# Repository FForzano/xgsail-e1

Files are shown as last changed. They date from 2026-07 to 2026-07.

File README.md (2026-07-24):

# XGSail-E1



E1 device firmware and hardware for [XGSail](https://github.com/FForzano/xgsail) —
an ESP32 sailboat tracker: GNSS + IMU + wind + pressure logging, an
ESP-NOW peer mesh for live fleet position sharing and on-course-side
(OCS) race-start detection, and uploads over the XGSail device
protocol — direct over WiFi, or relayed over BLE by the owner's phone
when WiFi isn't available.

> **xgsail-e1 is derived from `sailframes/core`**, the upstream hardware/
> firmware project. It is not a GitHub fork of that repository (see
> "Relationship to SailFrames Core" below for why, and where this
> content actually came from) — it's a from-scratch export of the E1
> device's firmware and hardware, reorganized into per-responsibility
> modules and stripped down to E1 only.

## What xgsail-e1 Is

xgsail-e1 is the firmware and PCB design for one specific device: **E1**,
an ESP32-based fleet tracker.

It provides:

- Firmware (`firmware/sailframes_edge/`) — GNSS/IMU/wind/pressure sensor
  reads, SD-card session logging, an ESP-NOW peer mesh with on-course-side
  (OCS) race-start detection, the XGSail device-protocol claim/upload flow
  (direct over WiFi and a BLE GATT relay for when WiFi isn't available),
  and a serial/telnet console.
- Hardware (`hardware/`) — the KiCad 8+ schematic, PCB layout, Gerbers,
  and BOM for the E1 board.
- Documentation (`docs/`) — the firmware's internal architecture, GNSS/RTK
  configuration and PPK post-processing workflow, and the current battery/
  display/power hardware.

The device talks to the XGSail backend through the hardware-agnostic
ingestion contract documented in xgsail's `docs/device-protocol.md`
(device claim, `DeviceKey` auth, presigned session uploads, and the BLE
relay contract for WiFi-less operation) — this repo implements that
contract, it doesn't redefine it.

## What xgsail-e1 Is Not

xgsail-e1 is **not** the software platform — users, roles, clubs, the
ingestion API, analytics, or the web/native apps. That's
[XGSail](https://github.com/FForzano/xgsail).

It is also not the general SailFrames Core hardware project: other
device families from that upstream (a Raspberry-Pi-based "Edge-S" unit,
a sealed-enclosure successor board, and a standalone BLE wind-sensor
accessory) are out of scope here on purpose — this repository is E1 only.

## Relationship to SailFrames Core

XGSail's own `xgsail` repository is itself a GitHub-level fork of
`sailframes/core`, the upstream hardware+software monorepo — before its
software layer was redesigned into what is now XGSail, that repository's
history contained `edge-e/` (the E1 device: this firmware + hardware),
`edge-b/` (a later, different hardware platform), and `edge-s/` (the
Raspberry-Pi device), alongside the cloud-side code that became XGSail's
backend/frontend/workers.

xgsail-e1 is an export of `edge-e/` from that history: the firmware and
hardware for E1 specifically, with the other device families and the
now-superseded cloud-side code left out, and the firmware's `#ifdef`s for
the non-E1 hardware variant removed rather than carried forward as dead
code. It is not a `git fork` of `sailframes/core` (GitHub only allows one
fork per repo per account, and that slot is already used by `xgsail`) —
its origin is recorded here in `docs/firmware-architecture.md` and this
README instead of in GitHub's fork metadata.

License: Apache 2.0, same as upstream and same as xgsail — no relicensing.

## Display

3.5" TFT dashboard, three nav layouts cycled live (console or BLE), plus
two race-committee-only panels for fleet OCS detection:

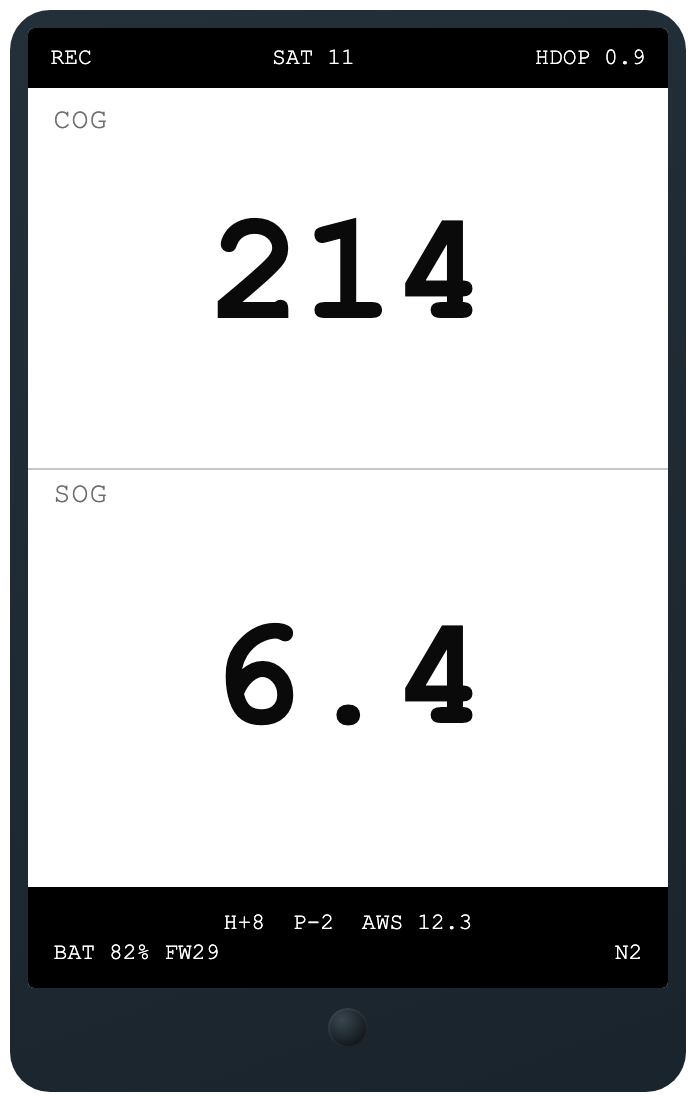
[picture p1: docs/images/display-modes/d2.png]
D2 nav display

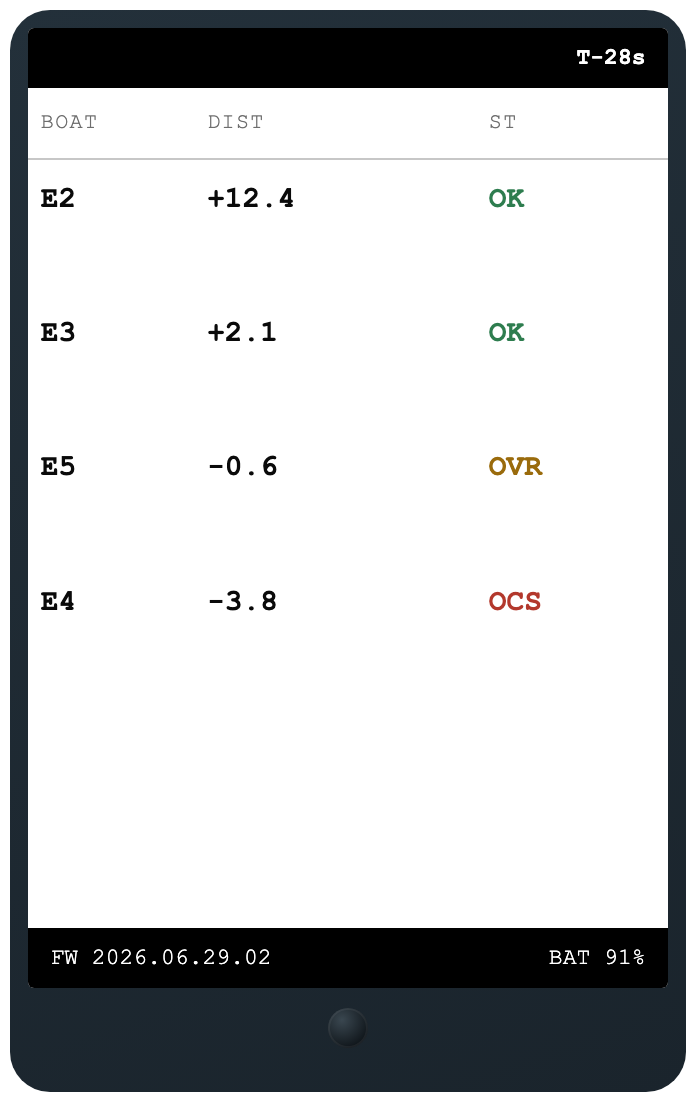
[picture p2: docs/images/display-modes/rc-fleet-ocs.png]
RC in-race OCS panel

<br>D2 — nav + wind (default) &nbsp;·&nbsp; RC panel — live OCS per boat

See `docs/hardware.md`'s Display section for all three nav modes and
both RC panels.

## Quick start

### Firmware

```bash
cd firmware/sailframes_edge
# Open in Arduino IDE, or build with PlatformIO
```

See `firmware/README.md` for board settings, library dependencies, pin
assignments, SD card setup, and the full serial/telnet console command
reference.

### Hardware (KiCad)

```bash
cd hardware
kicad kicad_sailframes-e1.kicad_pro
```

## Repository layout

`firmware/sailframes_edge/` (main sketch, one file/pair per
responsibility — see `CLAUDE.md` for the full module map) ·
`firmware/{e1_sd_card,i2c_scan,sailframes_e1_diag}/` (sample SD contents
and standalone bring-up sketches) · `hardware/` (KiCad project + fab
outputs) · `docs/{firmware-architecture,gnss-rtk,hardware}.md`.

## License

Apache 2.0.

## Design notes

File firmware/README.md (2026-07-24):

# SailFrames E1 Firmware

ESP32 fleet-tracker firmware: GNSS + IMU + wind + pressure logging, an
ESP-NOW peer mesh for live fleet position sharing and OCS (on-course-side)
race-start detection, uploads over the XGSail device protocol (direct
WiFi, or a BLE relay via the owner's phone when WiFi isn't available),
and a serial/telnet console.

## Hardware

| Component | Part | Interface |
|---|---|---|
| MCU | ESP32 DevKit V1 | — |
| GNSS | Waveshare LG290P | UART2, 460800 baud |
| IMU | BNO085 (Adafruit breakout, address 0x4B) | I2C |
| Pressure/temp | DPS310 (address 0x77) | I2C |
| Display | Hosyond 3.5" IPS ST7796U, 480x320 | SPI (VSPI) |
| Storage | MicroSD, standalone module | SPI (HSPI, separate bus from the display) |
| Wind sensor | Calypso Mini (BLE) | BLE (NimBLE) |
| Power | DWEII USB-C 5V boost converter + LiPo | 100K/100K divider on GPIO34 |
| Recording/pairing button | Momentary pushbutton, active-low | GPIO32, internal pull-up |

### Pin assignments (see `sailframes_edge/config.h`)

| ESP32 Pin | Function | Device |
|---|---|---|
| GPIO16 | UART2 RX | LG290P TX |
| GPIO17 | UART2 TX | LG290P RX |
| GPIO21 | I2C SDA | BNO085 + DPS310 |
| GPIO22 | I2C SCL | BNO085 + DPS310 |
| GPIO5 | SPI CS (VSPI) | TFT |
| GPIO2 | Data/Command | TFT |
| GPIO4 | Reset | TFT |
| GPIO25 | Backlight (PWM) | TFT |
| GPIO27 | SPI CS (HSPI) | SD card |
| GPIO14 | SPI CLK (HSPI) | SD card |
| GPIO35 | SPI MISO (HSPI) | SD card |
| GPIO13 | SPI MOSI (HSPI) | SD card |
| GPIO34 | ADC (battery divider) | LiPo voltage sense |
| GPIO32 | Digital in, pull-up (active-low) | Recording/pairing pushbutton |

The display and SD card are deliberately on separate SPI buses (VSPI vs.
HSPI) — sharing one bus caused visible flicker during SD writes.

## Building and flashing

Arduino IDE or PlatformIO, sketch directory `sailframes_edge/`:

- **Board:** ESP32 Dev Module
- **Upload speed:** 921600
- **Flash frequency:** 80 MHz
- **Partition scheme:** Custom — Arduino IDE: **Tools → Partition Scheme →
  "Custom"**, which uses the sketch-local `partitions.csv`. This is a
  dual-app OTA-capable table (two ~1.94MB app slots + `otadata`, no SPIFFS);
  the ~1.6MB image (TFT_eSPI + NimBLE + ArduinoJson + BNO08x/DPS310 +
  WiFi/TLS) links with ~330KB headroom. SPIFFS is dropped because this
  firmware stores everything on the SD card. The two slots are what the
  firmware's own OTA update flow (`docs/ota.md`) flashes between — a device
  previously flashed on the old No-OTA scheme must be reflashed once over
  USB to adopt this table.

### Libraries (Arduino Library Manager)

- **TFT_eSPI** — display driver (configured via `User_Setup.h` in this
  sketch directory, loaded automatically ahead of the library's own config)
- **Adafruit BNO08x** — IMU driver (SHTP protocol)
- **Adafruit DPS310** — pressure/temperature driver
- **NimBLE-Arduino** (pinned to 2.4.0 — see `docs/firmware-architecture.md`
  for why the version is pinned) — Calypso wind sensor BLE client
  (central role) and the device-protocol BLE relay GATT server
  (peripheral role), running concurrently
- **ArduinoJson** (7.x) — JSON building/parsing for the device-protocol
  HTTP calls (claim, session-uploads, health) and the BLE relay's
  characteristic payloads

ESP-NOW, WiFi, and SD support come from the ESP32 Arduino core (pinned to
3.3.7 — also documented in `docs/firmware-architecture.md`).

### Prebuilt binaries

`.github/workflows/firmware-release.yml` builds this sketch with
`arduino-cli` (same board settings and pinned versions as above) on every
`v*` tag, and on demand from the Actions tab. It attaches to the release:

- `...-merged.bin` — bootloader + partition table + app in one image,
  flashed at offset `0x0`
- `...-app.bin` / `...-bootloader.bin` / `...-partitions.bin` — the
  individual images, for flashing the app alone at `0x10000`
- `SHA256SUMS.txt`

Flashing a downloaded build needs only esptool (`pip install esptool`),
no toolchain:

```
esptool.py --chip esp32 --port /dev/ttyUSB0 --baud 921600 \
  write_flash 0x0 sailframes_edge-<version>-merged.bin
```

Flashing replaces the firmware only — `config.txt`, `device.txt` and the
recorded sessions live on the SD card and are untouched.

## Repository layout

```
sailframes_edge/       # Main sketch — see CLAUDE.md for the per-file module map
e1_sd_card/             # Sample imu_cal.txt / wind_mac.txt for the SD card
i2c_scan/               # Standalone I2C bus scanner sketch (bring-up/debug)
sailframes_e1_diag/     # Standalone board-bring-up diagnostic sketch
```

## SD card setup

1. Format FAT32 (32GB or less recommended).
2. Copy `sailframes_edge/config.txt` to the card's root and edit it:
   WiFi networks (`wifi1_ssid`/`wifi1_pass`, ...), `boat_id`, recording
   speed thresholds, `unit_role` (`racing_boat`, `rc_signal`, ...),
   `api_base_url` (the XGSail backend this device talks to), and
   `claim_code` (see "Claiming the device" below).
3. A `/wind_mac.txt` file (Calypso Mini MAC address) enables the wind
   sensor and speeds up reconnection — see `e1_sd_card/wind_mac.txt` for
   the format. Without it, the wind sensor is disabled.
4. `/imu_cal.txt` stores the heel/pitch zero-offsets saved by the `cal`
   console command — see `e1_sd_card/imu_cal.txt`.
5. `/device.txt` is firmware-owned (like `/boot.log`) — it holds the
   `device_id`/`device_api_key` written by a successful claim. Don't
   create or edit it by hand.

## Log files

Per session, under `/sf/<session-folder>/` (GPS-datetime named when a fix
is available, `session_NNN` otherwise):

```
<boat_id>_<date>_<time>_nav.csv    # 10 Hz: lat, lon, speed, course, sat, hdop, fix, hacc
<boat_id>_<date>_<time>_imu.csv    # 10 Hz: accel, gyro, linear accel, mag, heel, pitch, heading
<boat_id>_<date>_<time>_wind.csv   # 1 Hz, only when a wind sensor is paired
<boat_id>_<date>_<time>_pres.csv   # 0.1 Hz: pressure, temperature, min/max (gust window)
```

A recording session starts and stops manually — a short press of the
device's button, the console's `rec`/`stoprec` commands, or the BLE
relay's `start-rec`/`stop-rec` (`docs/ble-config.md`) — or ends on a
clean power-off. There is no GPS-speed auto-start/stop (see
`docs/hardware.md`'s "Button-triggered recording").

## Claiming the device

A device cannot upload anything until it's claimed (xgsail's
`docs/device-protocol.md` §2) — there is no auto-registration on first
upload. From the XGSail app, create a claim for this device to get a
one-time `claim_code`, then either:

- write it into `config.txt` as `claim_code=XXXXXXXX` before boot (the
  upload task redeems it automatically, once, the first time WiFi
  connects), or
- power the device on and run the `claim <CODE>` console command, or
- use the XGSail app's BLE relay (no WiFi needed at all — see "BLE relay"
  below).

Check status any time with the `device` console command. A lost
`device_api_key` needs a fresh key from the app (`rotate-key`) rewritten
onto the device by one of the methods above — the device cannot
regenerate its own key.

## Device-protocol upload

Files upload automatically once the device is stationary (speed below
~0.5 kt, or no GPS fix) for 30 seconds, the device is claimed, and a
configured WiFi network is in range — no manual step needed. Each of the
session's CSVs (nav/imu/wind/pres — whichever sensors were actually
present) uploads as its own call; a session missing a sensor (no wind
paired, no pressure chip) uploads exactly the files it has. Each file
gets a `.uploaded` marker so it's never re-sent by either upload path
(WiFi or BLE relay). Trigger a cycle immediately with the `upload`
console command, or check pending state with `status`.

By default (`config.txt`'s `auto_cleanup_uploads`, also settable live
over BLE — `docs/ble-config.md`), a file is deleted from the SD card
right after it uploads successfully, instead of sticking around for the
manual `cleanup`/`delup` console command. Turn it off if you'd rather
keep a local copy of every session regardless of upload state.

## BLE relay

Alongside direct WiFi upload, the device always advertises a BLE GATT
service (xgsail's `docs/device-protocol.md` §8) that the XGSail phone app
can use to relay the same claim + upload calls over Bluetooth — for a
device with no WiFi configured at all, or when WiFi is temporarily out of
range. It's a first-class path, not just a fallback: the service comes up
at boot regardless of WiFi state. See `docs/firmware-architecture.md` for
how `ble_relay.cpp` maps pending SD files onto the protocol's
`session_manifest`/`session_data` characteristics.

The same BLE service also lets a companion app configure the device
remotely — WiFi credentials, boat identity, recording thresholds, and
more — trigger IMU calibration, and start/stop a recording session, all
without pulling the SD card. This is firmware-specific, not part of
xgsail's device protocol — see `docs/ble-config.md` for the full spec.

A phone pairing for the first time (to claim the device or write any of
the above) needs the device's button held for the long-press pairing
window — see `docs/hardware.md`'s "Recording/pairing button" and
`docs/ble-config.md`'s "Pairing window" for why and how.

## Serial / telnet console

USB-serial always accepts commands. The telnet listener (port 23) is off
by default — enable it with the serial `telneton` command if you need to
debug over WiFi (see `sailframes_edge/config.h`'s `TELNET_ENABLED_DEFAULT`
for why it defaults off).

```
telnet <device-ip> 23
```

Commands (`help` prints this list from the device):

| Command | Description |
|---|---|
| `status` | Device status: GPS, IMU, SD, WiFi, uploads |
| `gps` / `gpsraw` / `gpscfg` | GNSS detail / raw NMEA / reconfigure |
| `imu` / `imutest` / `cal` / `calreset` | IMU detail, axis test, calibrate/reset |
| `pres` | Pressure/temperature reading |
| `rec` / `stoprec` / `recstate` | Manual recording control + state |
| `wind` / `windscan` / `blescan` / `bleinit` / `bledeinit` / `bleconnect <mac>` | Wind sensor BLE |
| `display` | Toggle display mode |
| `heap` | Memory status |
| `ls`, `list` / `cat <file>` / `cleanup` | SD card browsing + uploaded-file cleanup |
| `upload` | Manual device-protocol upload cycle now |
| `claim <CODE>` / `device` | Redeem a claim code / show external_id + claim status |
| `wifi` / `disconnect` / `reboot` | Network + power control |
| `hwid` / `role` / `flags` / `radiomode` | Identity/config/state readouts |
| `mesh` / `fleet` / `fleetwatch` / `classes` | ESP-NOW peer mesh + RC fleet OCS view |
| `ocs` / `race arm <pinLat> <pinLon> <rcLat> <rcLon> <secs>` / `race disarm` | OCS state machine |
| `health` | Push a health snapshot now |

See `docs/firmware-architecture.md` for what the mesh/OCS/device-protocol
commands actually do, and `docs/gnss-rtk.md` for the GNSS-specific ones.

## WiFi configuration

Up to 5 networks in `config.txt`, tried in order until one connects:

```
wifi1_ssid=Home-IOT
wifi1_pass=password1

wifi2_ssid=YachtClub
wifi2_pass=password2
```

## License

Apache 2.0.

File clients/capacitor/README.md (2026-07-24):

# @xgsail-e1/capacitor

Client-side **BLE transport for the E1** sailing tracker. It packages the
E1's GATT contract — service/characteristic UUIDs, wire types, and every
operation to talk to the device over Bluetooth LE — so any Capacitor app that
manages an E1 can reuse it instead of re-implementing the protocol.

This is the client half of the same contract the firmware in this repo
implements. See [`docs/ble-config.md`](../../docs/ble-config.md) for the
E1-specific configuration/calibration spec.

## Scope

**BLE transport (low level):** scan & discovery, connect/disconnect, read
`identity`, read/write `device_config`, read `status`, calibrate / start-rec /
stop-rec / manual OTA-update commands, and the session-relay primitives
(`readManifest`, `transferSession`, `ackUploaded`, `writeProvisioning`).

**Device management (high level):** `createE1Client({ backend, keyStore })`
gives you `claim(...)` and `uploadSessions(...)` — the full BLE-plus-backend
orchestration. The two seams are pluggable:

- **`E1Backend`** — the HTTP calls claim/upload end in. `httpBackend({ baseUrl })`
  is the ready-made implementation of the standard device-protocol (see
  [Backend contract](#backend-contract)); implement the interface yourself for
  a different server.
- **`E1KeyStore`** — where per-device keys are persisted. `secureStorageKeyStore()`
  (Capacitor Secure Storage) is the default; supply your own to store keys
  elsewhere.

Nothing here is tied to any particular app — point it at a base URL and go.

Native-only: every function no-ops on web (Web Bluetooth is unavailable on
iOS Safari and unreliable elsewhere), gated by `isNative()`.

## Install

```bash
npm install @xgsail-e1/capacitor
```

Peer dependencies (already present in a Capacitor app):

```bash
npm install @capacitor/core @capacitor-community/bluetooth-le
```

## Usage

### Configure & manage a device (claim + upload)

```ts
import { createE1Client, httpBackend, secureStorageKeyStore, scanForDevices } from "@xgsail-e1/capacitor";

const client = createE1Client({
  backend: httpBackend({ baseUrl: "https://app.example.com/api" }),
  keyStore: secureStorageKeyStore(), // Capacitor Secure Storage
});

// Claim a nearby device with a code, then relay its buffered sessions:
const [scanned] = await scanForDevices();
const { deviceId } = await client.claim(scanned, "ABC123");
const results = await client.uploadSessions(scanned, deviceId);
```

### Read status / edit config (low-level BLE)

```ts
import * as e1 from "@xgsail-e1/capacitor";

const devices = await e1.scanForDevices();
const status = await e1.withConnection(devices[0].bleId, () => e1.readStatus(devices[0].bleId));

// Live panel: hold one connection open, poll while mounted
await e1.connect(bleId);
const config = await e1.readConfig(bleId);
await e1.writeConfig(bleId, { display_mode: 2 });
await e1.disconnect(bleId);
```

`readStatus(...).firmware_version` is the device's running build
(`YYYY.MM.DD.N`). `E1Config` includes `ota_auto_update` (owner's opt-in for
automatic OTA firmware updates) and `ota_base_url` (which feed it checks) —
see the repo's `docs/ota.md`. Regardless of `ota_auto_update`,
`requestOtaUpdate(bleId)` (`control.ts`) triggers a manual check-and-apply from
any bonded phone; poll `readStatus(...).ota` for progress
(`checking`/`downloading`/`applying`/`up_to_date`/`suspended`/`error`) — a
successful update reboots the device, so there's no final reply on the control
characteristic itself. No update, automatic or manual, is ever attempted while
the device is recording.

### Custom backend or key store

Implement `E1Backend` / `E1KeyStore` and pass them to `createE1Client` — the
BLE relay logic is unchanged, only where it reads/writes differs.

## Backend contract

`httpBackend({ baseUrl })` speaks the E1 device-protocol (the same one the
firmware implements). A compatible server exposes:

| Call | Endpoint | Auth |
| --- | --- | --- |
| Confirm claim | `POST {baseUrl}/devices/claim/confirm` — body `{ external_id, claim_code }` → `{ device_id, device_api_key }` | none (the claim code is the credential) |
| Open session upload | `POST {baseUrl}/devices/me/session-uploads` — body `{ started_at, ended_at, filename, boat_id?, activity_id? }` → `{ session_upload_id, upload_url }` | `Authorization: DeviceKey <device_api_key>` |
| Store bytes | `PUT <upload_url>` (self-authorising presigned/HMAC URL) | none |
| Finalize | `PATCH {baseUrl}/devices/me/session-uploads/{id}` — body `{ is_final: true }` | `Authorization: DeviceKey <device_api_key>` |

`filename` must keep the file's real sensor-type suffix (nav/imu/wind/pres) —
the ingestion side keys sensor type off it. See `docs/ble-config.md` for the
BLE side of the same flow.

## Build

```bash
npm install
npm run build   # tsc → dist/ (ESM + .d.ts)
```

## License

Apache-2.0

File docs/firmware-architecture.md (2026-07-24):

# Firmware architecture

How the E1 firmware is put together: the dual-core split, the XGSail
device-protocol claim/upload flow (WiFi and its BLE relay fallback), the
ESP-NOW peer mesh, on-course-side (OCS) race-start detection, and unit
roles. Written against the actual module layout in
`firmware/sailframes_edge/` (see `CLAUDE.md` for the file-per-module map)
— if something here and the source disagree, the source wins.

## Dual-core split

`setup()` creates two additional FreeRTOS tasks pinned to **Core 0**,
leaving Arduino's own `loop()` running on **Core 1**:

- `uploadTaskFunc` (`upload.cpp`) — WiFi connect, the device-protocol
  session-upload cycle, claim attempts, and the periodic health-snapshot
  push. Everything that touches the WiFi/HTTP stack lives here so Core 1's
  sensor reads and SD logging are never blocked by a slow upload.
- `diagnosticsTask` (`upload.cpp`) — an independent heartbeat that keeps
  running even if Core 1 hangs, printing `g_loopSection` (Core 1's last
  checkpoint, `shared_state.h`) and `g_uploadSection` (Core 0's, in
  `upload.h`) so a watchdog panic's backtrace can be matched to a human-
  readable "stuck here" location instead of just a raw stack trace.

SD-card access is shared between the two cores (Core 1 logs, Core 0
reads closed session files to upload) and serialized by `sdMutex`
(`shared_state.h`) — the upload task only ever touches files after
`logging` has already closed them, never the actively-written session.

`wifiBusy` (`shared_state.h`) is the other cross-core signal: while Core 0
is mid-WiFi-work, Core 1 must not touch the WiFi/LWIP stack (telnet,
`WiFi.*` calls) — under sustained traffic, LWIP mutex contention between
the two cores has hung the device in the field. Every radio-sharing
subsystem (ESP-NOW mesh, RTK relay, telnet) checks this gate before
touching the radio.

## ESP-NOW peer mesh (`mesh.{h,cpp}`)

Every unit broadcasts its own boat-state at 2 Hz (`MESH_BROADCAST_INTERVAL_MS`)
on a fixed channel (`MESH_CHANNEL`), unencrypted, to the broadcast address
— there's no peer registration or per-boat pairing. `meshOnReceive()`
(the ESP-NOW receive callback, running in the WiFi task context) parses
the packet and updates an in-memory peer table (`g_mesh_peers`,
`MESH_PEER_MAX` = 32 slots); peers not heard from in `MESH_PEER_EXPIRY_MS`
(30 s) are dropped.

Wire format (`mesh.h`): a 16-byte `MeshHeader` (magic, version, message
type, sequence, sender ID — an FNV-1a hash of `boat_id`, stable across
reboots and MAC changes) followed by a per-message-type payload. Field
widths are deliberately small — `sog_cm_s`/`cog_deg10`/`heading_deg10` as
scaled `int16_t`, `heel_deg` as `int8_t` — to keep the aggregate mesh
traffic (up to ~25 boats × 2 Hz) well inside ESP-NOW's per-packet budget.
Message types in use: `MSG_BOAT_STATE`, `MSG_RACE_ARMED`,
`MSG_INDIVIDUAL_RECALL`, and `MSG_RTCM_FRAG` (the RTK relay, see
`docs/gnss-rtk.md`) — the enum also reserves a few message types that
aren't sent by this firmware.

## OCS (on-course-side) detection (`ocs.{h,cpp}`)

Per-boat, boat-local: `ocsArm()` records the start line (PIN and RC
endpoints, both `double` lat/lon) and start time. Once armed, `ocsTick()`
runs at up to `OCS_TICK_INTERVAL_MS` (100 ms, matching the GPS fix rate):
it projects the boat's bow position (GPS position advanced by
`bow_offset_m` along the current heading — GPS course over ground above
2 kt, IMU heading below that speed, since COG is unreliable at low
speed) onto the start line, computing a **signed perpendicular
distance** — positive is the pre-start side. Past the start time, a
distance beyond `OCS_THRESHOLD_M` (0.5 m) latches `over_line`; clearing
requires being back past `OCS_CLEAR_THRESHOLD_M` for
`OCS_CLEAR_DWELL_MS` (2 s) continuously, so a boat bobbing right at the
line doesn't flicker in and out of the OCS state.

The `rc_signal` unit additionally runs `rcComputeFleetOCS()`: the same
geometry applied to every mesh peer's last-known position, using the
RC's own (authoritative) line endpoints and each boat's `bow_offset_m`
looked up from `/sf/classes.csv` (`loadClassRegistry()`/
`bowOffsetForSender()` — falls back to `OCS_BOW_OFFSET_M` for boats not
in the registry). When the RC's computation calls a boat OCS, it
broadcasts `MSG_INDIVIDUAL_RECALL`; the target boat's `ocsForceOver()`
sets `over_line = true` regardless of what its own local computation
said — **the RC's call is authoritative**, and a boat's local vs. the
RC's view disagreeing is logged to `/sf/ocs_disagree.log` for post-race
review rather than acted on live.

`fleetWatchTick()` (`ocs.cpp`) is a non-blocking live serial dashboard
(toggle with the `fleetwatch` console command) for watching the whole
fleet's OCS state from an RC unit's USB-serial console during a start
sequence.

## Unit roles and radio mode (`v2_types.h`)

`UnitRole` (`config.txt`'s `unit_role`, read at boot in
`loadConfig()`/`config.cpp`): `racing_boat` (default), `rc_signal`
(computes fleet OCS, is the RTK base when RTK is on), `rc_pin`, `mark`,
`committee_chase`, `spare`. `RadioMode` (`g_radio_mode`:
`MODE_BOOT`/`MODE_IDLE`/`MODE_DOCK`/`MODE_RACING`/`MODE_RC_ACTIVE`) is
tracked and logged on transition (`radioModeTransition()`, `mesh.cpp`)
for `/boot.log` forensics; this repo's build is E1-only, so
`HardwarePlatform` (`g_hw`) is always `HW_E1` regardless of what
`hardware_platform` says in `config.txt` (kept in `Config` for on-disk
compatibility with the wider SailFrames Core fleet, which also has other
hardware platforms — see `README.md`).

## Device protocol: identity, claim, and uploads (`device_auth.{h,cpp}`, `upload.{h,cpp}`)

Implements xgsail's `docs/device-protocol.md` exactly — that document is
the source of truth for the wire shapes; this is how the E1 firmware
happens to drive them.

- **Identity** (`device_auth.h`'s `externalId()`): the ESP32's WiFi MAC
  address, stable across reboots, requiring no configuration.
- **Claim** (`claimDevice()`): `config.txt`'s `claim_code=` (read once at
  boot by `uploadTaskFunc` as soon as WiFi first connects) or the
  `claim <CODE>` console command call `POST /api/devices/claim/confirm`.
  On success, `device_id` + `device_api_key` persist to `/device.txt` — a
  firmware-owned file, parallel to `/boot.log`, never the user-edited
  `config.txt`. `isClaimed()` only requires a usable `device_api_key`;
  `device_id` is display metadata, not a precondition — the BLE relay's
  `provisioning` characteristic (below) only ever delivers the key.
- **Authenticated calls** (`apiRequest()`): every `/api/devices/me/...`
  call adds `Authorization: DeviceKey <key>`. Chooses `WiFiClientSecure`
  or `WiFiClient` based on `config.api_base_url`'s scheme.
- **Uploads** (`uploadFile()`, called once per pending SD file — nav/imu/
  wind/pres CSVs are independent files, uploaded independently, matching
  the backend's one-`session_upload`-row-per-file model): `POST
  /api/devices/me/session-uploads` with `is_final=true` (E1 never uses
  the incremental/chunked case), then a manually-chunked `PUT` of the raw
  bytes to the returned presigned `upload_url` (own chunk loop rather
  than `HTTPClient::sendRequest`, so the task watchdog gets fed every
  chunk on multi-minute transfers). A PUT failure `PATCH`es the upload as
  `"failed"`; success sends no `PATCH` at all — `is_final` was already
  true on the opening `POST`, and the object-storage `PUT` completing is
  what actually finalizes the data server-side.
- **Health** (`uploadHealthSnapshot()`): the 5-field `POST
  /api/devices/me/health` snapshot, once per boot. The reported
  `firmware_version` is what makes the running build visible server-side.
- **OTA check** (`checkForFirmwareUpdate()`, `docs/ota.md`): runs once per
  boot (and on subsequent health-check WiFi wakes) right after the health
  snapshot, reusing that same WiFi window. Gated on `config.ota_auto_update`
  and never while `logging` (recording). Fetches
  `<ota_base_url>/manifest.json`, and on a strictly newer `version` streams
  the image into the inactive OTA slot (`partitions.csv`'s dual app0/app1),
  verifies its SHA256 before committing, and reboots into it. A manual
  check-and-apply can also be triggered any time (even with
  `ota_auto_update` off) via the BLE `control` `ota-update` command
  (`docs/ble-config.md`); either path refuses outright, or suspends an
  in-progress download, the moment recording starts.
- Sessions with only some sensors present (no wind sensor paired, no
  pressure chip detected) upload exactly the files that exist — nothing
  waits for or assumes all four CSVs.

## BLE relay (`ble_relay.{h,cpp}`)

A NimBLE **peripheral** GATT server implementing `docs/device-protocol.md`
§8: lets the owner's phone app relay the claim + session-upload calls
above over Bluetooth instead of WiFi. This is a first-class upload path,
not a WiFi-down fallback — `bleRelayInit()` runs unconditionally from
`setup()` and brings up BLE itself (`NimBLEDevice::init()`) if the
wind-sensor central role (`wind_sensor.cpp`) hasn't already, since a boat
with no wind sensor paired and no WiFi configured still needs a way in.
NimBLE-Arduino runs both roles concurrently (`sailframes_edge.ino`'s
`CONFIG_BT_NIMBLE_ROLE_*` — central for the Calypso wind sensor, peripheral
for this relay).

Bonding itself is off by default (`bleRelayInit()`'s
`NimBLEDevice::setSecurityAuth(false, false, true)`) — a not-yet-bonded
phone can still connect, but a write to `provisioning` or `device_config`
(the two characteristics that can carry a secret: `device_api_key`, WiFi
password) is rejected unless this connection is already a recognized
bond, or `button.cpp`'s long-press handler has opened a timed pairing
window (`bleOpenBondWindow()`, `config.h`'s `BLE_BOND_WINDOW_MS`, flips
bonding to `setSecurityAuth(true, false, true)` for the window's
duration) — see `docs/hardware.md` for the button and
`docs/ble-config.md` for the full spec. `bleRelayTick()` flips bonding
back off once the window expires. MITM stays off throughout (`Just
Works` pairing) since this device never calls `setSecurityIOCap()` — it
has no display/buttons to satisfy MITM's passkey/confirmation exchange,
and the pairing window (physical presence at the boat) is the actual
protection against an unwanted bond, not MITM.

Each pending SD file (same file-driven pending list `upload.cpp` walks) is
one `session_manifest` entry, keyed by its SD path as the manifest's
`session_id` — the device never learns the backend's real
`session_id`/`session_upload_id`, since per the protocol it's the phone
app that calls `session-uploads`/`PUT`/`PATCH` itself; the device only
serves its own file inventory (`session_manifest`) and streams bytes on
request (`session_data`, notified in `bleRelayTick()` from the main
loop, sequence-indexed 4KB-ish chunks sized to the connection's actual
negotiated MTU). `control`'s `ack-uploaded` reuses `upload.cpp`'s own
`.uploaded` marker (`markUploaded()`) — a file relayed over BLE is never
re-offered by either upload path afterward. `provisioning` (the only
characteristic that can carry `device_api_key`) and `device_config`'s
write are the two characteristics gated by the pairing window described
above.

The same service also carries E1-specific extensions beyond
`docs/device-protocol.md` §8: a `device_config` characteristic for live
remote configuration (WiFi credentials, boat identity, recording
thresholds, RTK enable, ...), two extra `control` commands
(`calibrate`/`calibrate-reset`) for IMU calibration, and a read-only
`status` characteristic exposing live runtime state (battery, WiFi, GPS,
sensor presence, wind reading, recording activity) — the same fields the
console's `status` command prints, just as JSON. Full field-by-field
spec in `docs/ble-config.md` — not duplicated here. Every `device_config`
field applies live, no reboot, by calling the small refresh helper its
owning module already exposes (`applyUnitRole()`,
`applyRecordingThresholds()`, `forceWindReconnect()`, `gnssConfigure()`,
`boatIdHash()`) rather than requiring a fresh `loadConfig()` pass.

Because BLE callbacks run on the NimBLE host's own FreeRTOS task — a
third execution context beyond Core 1's `loop()` and Core 0's upload
task — every SD access reachable from any characteristic's callback
(not just the new ones) takes `sdMutex` with a short skip-if-busy
timeout, the same convention `storage.cpp`'s `appendBootLog()` and
`upload.cpp`'s `countPendingUploads()` already use.

## Console (`console.{h,cpp}`)

One command dispatcher (`processCommand()`) shared by USB-serial
(always on) and telnet (off by default — see `firmware/README.md` for
why, and the full command reference). Status/debug commands read state
directly out of the owning module (`gps`, `imu`, `battery`, `g_ocs`,
`g_mesh_peers`, ...) rather than duplicating it — if you add a command
that needs a new piece of state, that state belongs in its owning
module's header, not a new global in `console.cpp`.

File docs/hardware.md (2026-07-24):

# Hardware reference

The current battery/power, display, and recording-control setup, as
implemented in `firmware/sailframes_edge/` (`config.h`, `battery.cpp`,
`display.cpp`, `recording.cpp`) and the KiCad project in `hardware/`.
Earlier hardware revisions (an OLED display, a different battery pack
and voltage divider, a momentary power button with deep-sleep) are not
described here — see "Superseded designs" at the end if you're trying to
make sense of an older E1 unit in the field.

## Power

**No software power control at all.** A hardware SPDT slide switch cuts
all power to the board directly — there's no deep sleep, no button-hold
shutdown sequence, and no GPIO involved in powering the unit off. This is
deliberate: the firmware's own header comment states the design plainly —
*"Power control: Hardware switch on boost converter. No software deep
sleep — hardware switch cuts all power when OFF."* The only thing
software does around a power-off is make sure it doesn't happen mid-write:
`updateRecordingState()`'s `REC_STOPPING` path and `handleLowBattery()`
both flush and close any open session files before anything else, so a
switch flip mid-race doesn't corrupt the CSV in progress.

### Battery monitoring

- **Divider**: 100 kΩ / 100 kΩ from the LiPo's B+ straight to GPIO34
  (`BATT_VOLTAGE_PIN`, ADC1 — input-only, no pull-up, avoids ADC2's WiFi
  conflict). Nominal ratio is 2.0; the firmware uses a calibrated
  `BATT_DIVIDER_RATIO = 2.25` (`battery.cpp`) to correct for the ESP32
  ADC's non-linearity (empirically: a multimeter-measured 4.165 V read as
  3.70 V through the raw divider math, so `4.165 / 3.70 * 2.0 = 2.25`).
  16 averaged samples per read (`BATT_SAMPLES`) smooth out ADC noise.
- **Percent estimate**: a piecewise-linear lookup table over the LiPo
  discharge curve (`getBatteryPercent()`), not a straight voltage-to-percent
  line — the curve is genuinely non-linear (steep at both ends, flat in
  the middle), so a linear mapping over- or under-reports charge in the
  middle of the range:

  | Voltage | 4.20 | 4.15 | 4.10 | 4.05 | 4.00 | 3.90 | 3.80 | 3.70 | 3.60 | 3.50 | 3.40 | 3.30 |
  |---|---|---|---|---|---|---|---|---|---|---|---|---|
  | Percent | 100 | 95 | 85 | 75 | 65 | 50 | 35 | 20 | 12 | 6 | 2 | 0 |

- **Critical/low-battery behavior**: `isBatteryCritical()` fires below
  3.3 V (and only when the reading is plausible — above 0.5 V — so an
  unconnected/faulty sense line doesn't false-trigger). `handleLowBattery()`
  then flushes and closes any open session files, paints a red "LOW
  BATTERY / Flip power switch to OFF" screen, and halts in a `delay(1000)`
  loop — recovery is the operator flipping the hardware switch, not an
  automatic power-off, since there's no software path to cut power.

### Button-triggered recording

Recording start/stop is manual, not GPS-speed-triggered: a short press of
the physical button (`button.cpp`, `BUTTON_PIN` below) toggles
`recording.h`'s `startRecording()`/`stopRecording()` — same entry point
as the console's `rec`/`stoprec` commands and the BLE relay's `control`
`start-rec`/`stop-rec` commands (`docs/ble-config.md`). There is no
auto-start and no auto-stop on speed; a session runs until the operator
explicitly stops it (button, console, or app) or powers off (the slide
switch, which flushes and closes any open session files first — see
"Power" above). `config.start_speed_knots` survives only as the
"boat is moving" heuristic `upload.cpp` uses to abort an in-progress
upload cycle, not as a recording trigger — see
`docs/firmware-architecture.md` for the OCS/mesh context this recording
state feeds into, and `firmware/README.md` for the resulting log files.

### Recording/pairing button

A momentary pushbutton, active-low: one leg to `BUTTON_PIN` (GPIO32),
the other to GND, using the ESP32's internal pull-up (no external
resistor). `button.cpp` debounces it (`BUTTON_DEBOUNCE_MS`, 30 ms) and
dispatches two gestures:

- **Short press** — toggles recording (above).
- **Long press** (held past `BUTTON_LONG_PRESS_MS`, 2 s) — opens a
  60-second BLE pairing window (`BLE_BOND_WINDOW_MS`,
  `ble_relay.cpp`'s `bleOpenBondWindow()`) during which a new phone can
  complete its first bond; outside the window, a not-yet-bonded
  connection can't write the characteristics that carry secrets
  (`device_api_key`, WiFi password). See `docs/ble-config.md` for the
  full pairing-window spec. This requires physical presence at the boat
  to pair a new phone, rather than anyone in BLE range being able to.

## Display

**Hosyond 3.5" IPS ST7796U TFT, 480×320, SPI** (`TFT_eSPI`, configured via
`firmware/sailframes_edge/User_Setup.h`). Portrait orientation
(`tft.setRotation(2)`), inverted colors (`tft.invertDisplay(true)` — this
specific panel needs it for correct colors), PWM-dimmable backlight on
GPIO25 (`TFT_BL_PIN`) — full brightness while recording
(`TFT_BL_DUTY_RECORDING`, ~80%) and dimmed otherwise
(`TFT_BL_DUTY_IDLE`, ~50%) to save power, since the backlight is the
single largest current draw in the system.

The TFT and the microSD card are on **separate SPI buses** — the display
on the default VSPI bus, the SD card on HSPI with its own explicit pins
(`SD_CS_PIN`/`SD_CLK_PIN`/`SD_MISO_PIN`/`SD_MOSI_PIN` in `config.h`).
This is deliberate, not incidental: sharing one bus between the two
caused visible display flicker during SD writes on an earlier board
revision.

Three nav display modes exist (`display.cpp`'s `updateDisplayD1/D2/D3`,
cycled with the `display` console command, or set persistently via
`device_config`'s `display_mode` field over BLE — see `docs/ble-config.md`),
plus two RC-only panels (`drawRcFleetPanel`/`drawRcPreRacePanel`) that take
over the screen in place of the nav display while the unit's role is
`rc_signal` — see `docs/firmware-architecture.md` for what those panels
show and why.

The renders below are pixel-accurate reconstructions of `display.cpp`'s
layout (coordinates, dividers, colors) with sample data standing in for
live sensor readings — not photos of a running board.

**D1 — simple**
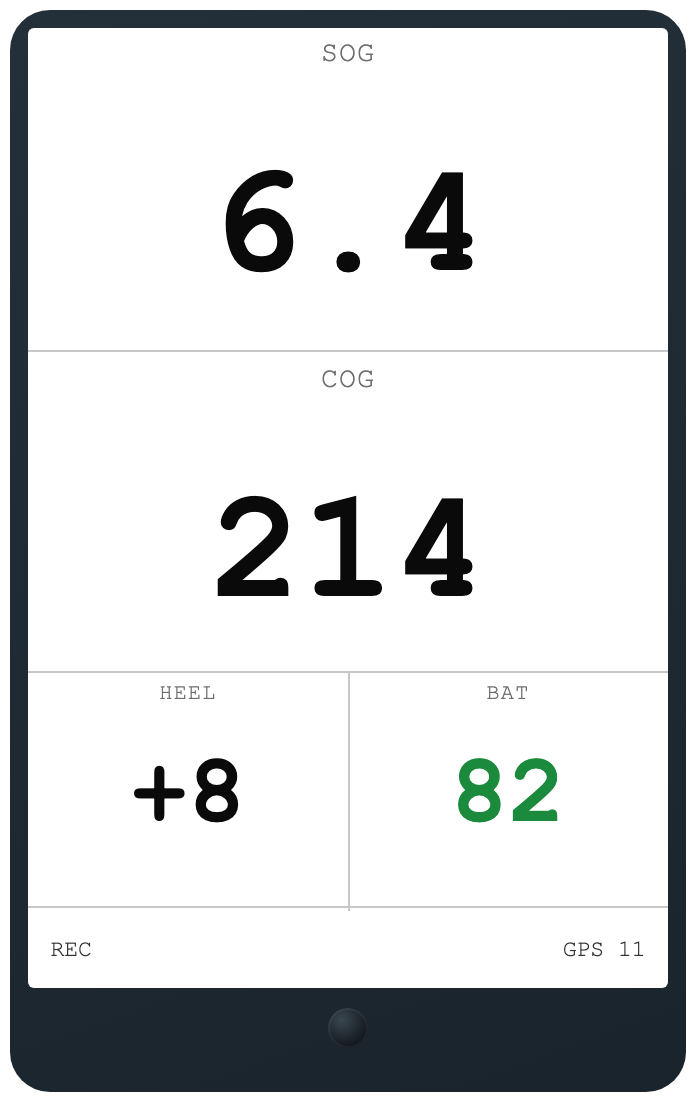
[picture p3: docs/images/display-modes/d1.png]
D1 display mode
<br>
<br>SOG/COG at full size, heel + battery below. Built for sunlight
readability, nothing else on screen.

**D2 — nav + wind (default)**
<br>D2 display mode
<br>COG over SOG, status bar with fix/sat/HDOP, bottom bar with
heel/pitch/wind/battery/upload — plus signed distance-to-line
(`L+5.2m`) once a race is armed.

**D3 — wind focus**
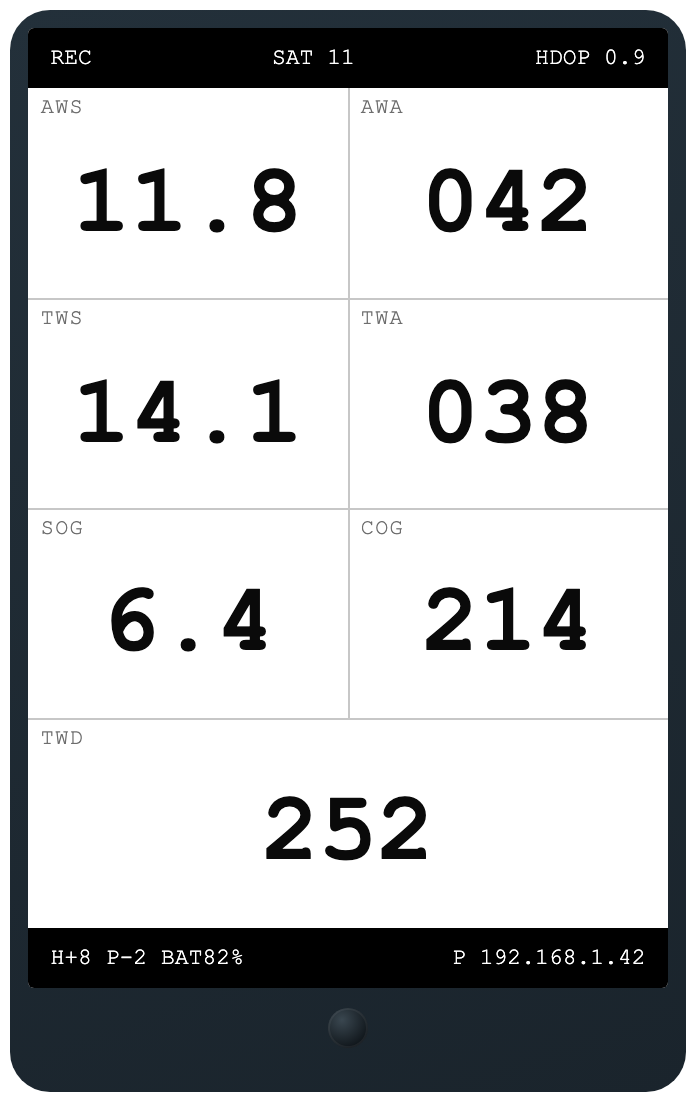
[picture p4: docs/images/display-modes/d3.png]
D3 display mode
<br>
<br>4×2 grid: apparent + true wind (speed/angle), SOG/COG, true wind
direction full-width at the bottom.

**RC pre-race panel**
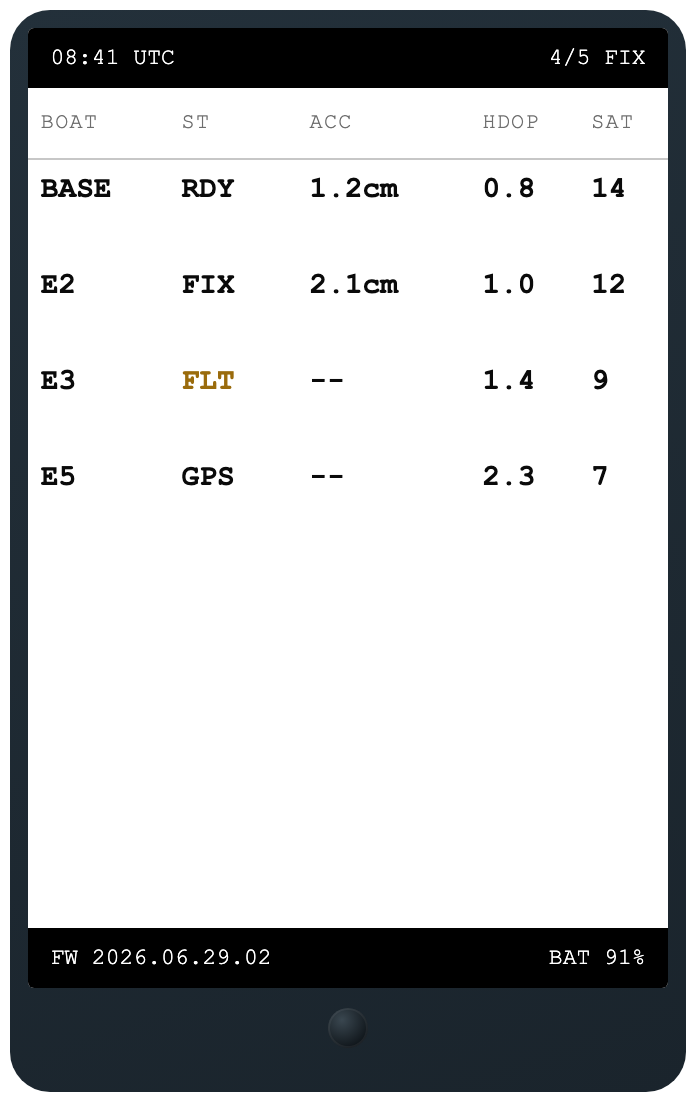
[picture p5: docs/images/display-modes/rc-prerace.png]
RC pre-race panel
<br>
<br>`rc_signal`-only: one row per connected peer — fix quality, accuracy,
HDOP, sat count — with a fleet-readiness "N/M FIX" gauge up top.

**RC in-race panel**
<br>RC in-race OCS panel
<br>Live signed distance-to-line and OCS state per boat (OK / OVR / OCS),
start countdown top-right.

**Boat-side OCS alarm**
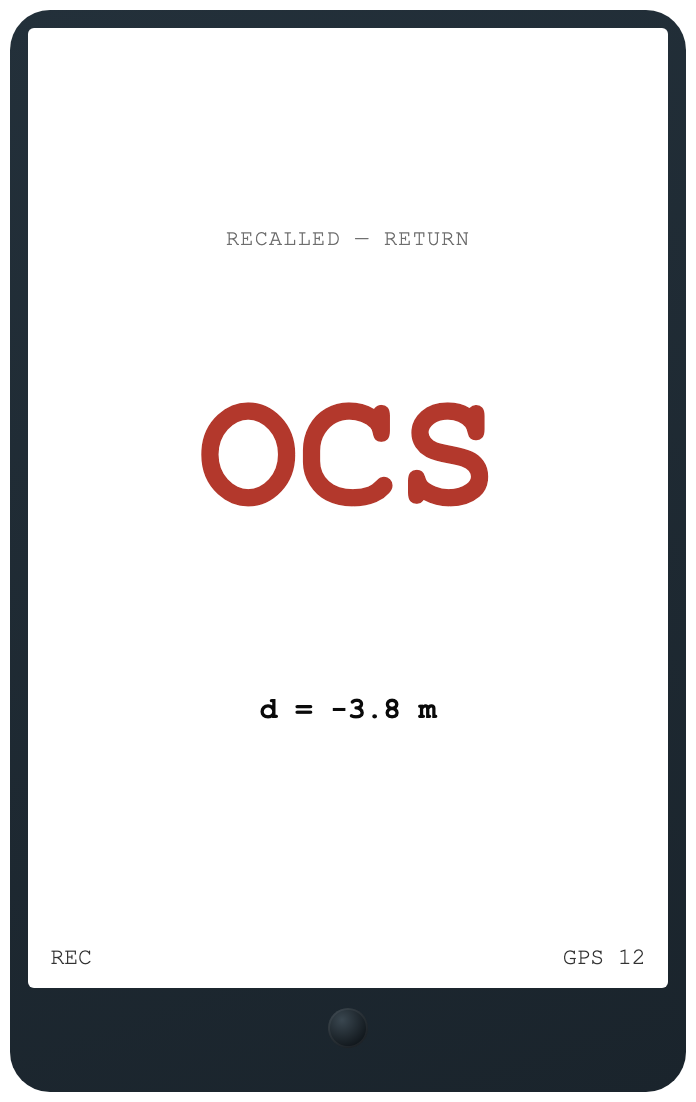
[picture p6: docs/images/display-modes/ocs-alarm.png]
Boat-side OCS alarm
<br>
<br>Takes over the nav display when the RC recalls this boat — the RC's
call is authoritative regardless of the boat's own local computation.

## Superseded designs (for context only — not what's on the board today)

Earlier E1 hardware revisions used a 2.42" SSD1309 OLED (128×64,
monochrome) instead of the TFT — replaced because it was unreadable
through polarized sunglasses and too small for a multi-value dashboard —
and a different battery/divider combination (first a PowerBoost-style
boost converter with a 200Ω/200Ω divider drawing a continuous ~10 mA,
later corrected to the 100 kΩ/100 kΩ divider described above once the
continuous drain was recognized as wasteful). An even earlier revision
used a momentary pushbutton (ESP32 deep sleep, wake-on-button) rather
than the hardware slide switch — none of this is present in the current
firmware or the KiCad project in `hardware/`; it's noted here only so a
differently-wired older unit doesn't look like a bug.

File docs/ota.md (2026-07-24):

# OTA firmware updates

The E1 can fetch and apply firmware updates over WiFi, either automatically
(opt-in, once-per-boot) or on demand from the owner's phone over BLE. It talks
to a public, unauthenticated OTA feed — the same manifest shape xgsail's own
`ota-service` uses for native-app bundles — and verifies the downloaded image's
SHA256 before ever committing it to flash.

## Why the partition table had to be decided up front

OTA needs two application slots (A/B): the device runs from one, writes the
new image into the other, and boot-swaps. The board's original `no_ota` scheme
had a single app slot — impossible to OTA onto, and a partition table can't be
changed by an update that runs *inside* that table. So the dual-app table
(`firmware/sailframes_edge/partitions.csv`, selected by `PartitionScheme=custom`
in the build FQBN) was adopted ahead of implementing OTA itself, to avoid ever
needing a fleet-wide USB reflash:

| Name | Type | SubType | Offset | Size | Notes |
|---|---|---|---|---|---|
| nvs | data | nvs | 0x9000 | 0x5000 | WiFi radio calibration store |
| otadata | data | ota | 0xe000 | 0x2000 | active-slot selector |
| app0 | app  | ota_0 | 0x10000 | 0x1F0000 | ~1.94 MB app slot A |
| app1 | app  | ota_1 | 0x200000  | 0x1F0000 | ~1.94 MB app slot B |

SPIFFS is dropped entirely (this firmware stores everything on the SD card,
`storage.cpp`) — reclaiming its 2 MB is what makes room for a second app slot
on 4 MB flash. The current image is ~1.6 MB, leaving comfortable headroom per
slot. Offsets line up with the release workflow's `esptool merge_bin` step
unchanged: the app lands at `0x10000` (= `app0`) and `boot_app0.bin` at `0xe000`
(= `otadata`).

> **One-time reflash of already-deployed devices.** A device flashed on the old
> `no_ota` table must be reflashed once over USB with the new merged image to
> adopt this table — a partition table can't rewrite itself.

## Config

| Field | Default | Meaning |
|---|---|---|
| `ota_auto_update` | `false` | Owner opt-in for automatic checks. Independent of the manual BLE trigger below, which works either way. |
| `ota_base_url` | `https://xgsail.com/ota` | Base URL of the firmware feed. Override for staging/self-hosted. |

Both are on-SD (`config.txt`) and live over BLE `device_config`
(`docs/ble-config.md`).

## Manifest contract

`GET <ota_base_url>/manifest.json` — public, **no auth** (firmware isn't a
secret; integrity is the SHA256 check below). Same response shape as xgsail's
`ota-service` (which serves native-app bundle manifests the same way):

```
200 OK
{ "version": "2026.08.01.01", "url": "https://.../app.bin", "checksum": "<sha256 hex>" }
```

or `{}` — nothing published / device is already current. `version` follows the
firmware's `YYYY.MM.DD.N` scheme (`config.h`'s `FW_VERSION`), compared as a
tuple against the running build — only a strictly newer build triggers a
download. A malformed/missing version on either side is treated as "not
newer" (fail closed — never flash on ambiguous data).

## Flow (`ota.cpp`)

1. **Trigger.** Either automatic — `checkForFirmwareUpdate()`, called once per
   boot (and on each subsequent health-check WiFi wake) from the Core-0 upload
   task (`upload.cpp`'s `uploadTaskFunc()`), gated on `config.ota_auto_update`
   — or manual, via the BLE `control` `ota-update` command (see below), which
   runs regardless of that flag.
2. **Manifest.** `otaFetchManifest()` GETs `manifest.json` and parses
   `version`/`url`/`checksum`.
3. **Version compare.** `otaVersionIsNewer()` parses both versions with the
   same `sscanf("%d.%d.%d.%d", ...)` pattern `display.cpp`'s `fwShortTag()`
   uses and compares the tuples.
4. **Download + flash.** `otaDownloadAndApply()` streams the image via
   `HTTPClient`/`Update.h` straight into the inactive OTA slot
   (`Update.begin()` targets the next slot automatically), computing a running
   SHA256 (`mbedtls_sha256_*`) as it writes. Uses the same watchdog-fed,
   stall/ceiling-guarded chunk loop shape as the session-upload path's
   `putFileBytes()`.
5. **Verify before commit.** The computed SHA256 is compared against the
   manifest's `checksum` **before** `Update.end()` is called. A mismatch aborts
   the update — the device keeps running the current (still-active) slot.
6. **Apply.** `Update.end(true)` sets the new slot as the boot partition;
   `ESP.restart()` reboots into it. The bootloader automatically rolls back to
   the previous slot if the new image fails to boot.

## Recording gate (hard requirement)

An OTA flash must never contend with an active recording for SD/CPU/WiFi:

- **Won't start:** `checkForFirmwareUpdate()` and the manual path both refuse
  outright while `logging` (`storage.h`) is true.
- **Suspended if already running:** the download loop polls `logging` every
  chunk (same pattern as `putFileBytes()`'s abort checks) and aborts the
  transfer the moment a recording starts, reporting state `"suspended"` rather
  than `"error"`. It is retried on a later WiFi window — automatically if
  `ota_auto_update` is on, or the next time the owner manually triggers it.

## Manual trigger over BLE

The `control` characteristic's `ota-update` (alias `ota-check`) command
queues an immediate check-and-apply, usable from **any bonded phone at any
time** — no pairing-window requirement, unlike `device_config` writes, since
it doesn't touch persisted config. The device refuses it outright (with
`{"ok": false, "message": "recording in progress"}`) while recording.

Because a successful update reboots the device, there is no final reply on
`control` itself — the ack only confirms the check was queued. Progress and
outcome are surfaced instead in the `status` characteristic's `ota` object
(`docs/ble-config.md`):

```json
"ota": { "state": "downloading", "progress": 42 }
```

`state` is one of `idle` / `checking` / `up_to_date` / `downloading` /
`applying` / `suspended` / `error`; `progress` (0-100) is present only while
downloading; `message` carries a short detail on `error`/`suspended`.

## Security: SHA256 only, no secure boot

Deliberately no secure boot, no image signing, no flash encryption — only the
SHA256 check above. Rationale:

- Secure boot v2 requires burning **irreversible eFuses** at flash time,
  signing every build (including dev builds), and careful key management —
  with a real risk of permanently bricking a device if keys are lost.
- It defends against an attacker with **physical access to the flash**
  injecting firmware or reading firmware IP off the chip. That threat isn't
  compelling for a sailboat tracker, which holds no secrets on flash beyond a
  per-device `DeviceKey` that is already revocable server-side.
- The realistic OTA threat — a **corrupted or tampered image in transit** — is
  fully covered by verifying the SHA256 before committing the image.

Note that HTTP/TLS is currently `setInsecure()` in `device_auth.cpp` (the
ESP32 core 3.3.7 TLS stack is unreliable), so certificate validation is not a
transport guarantee today — which is exactly why the SHA256 manifest check is
the **primary** integrity control for OTA, not a secondary one. If the threat
model ever changes, secure boot cannot be retrofitted onto deployed devices; it
would require a hardware/manufacturing decision for new units.

## Server side (xgsail repo)

The firmware feed is expected to live alongside xgsail's existing
`ota-service` (native-app bundle updates) — same manifest shape
(`version`/`url`/`checksum`, `{}` = up to date), same public/no-auth posture,
serving from the same object storage. Standing up
`https://xgsail.com/ota/manifest.json` for firmware builds (populating it from
the firmware release workflow's app binary + its SHA256) is server-side work
in that repo, not this one.

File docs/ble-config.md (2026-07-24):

# BLE device configuration

An E1-specific extension to the BLE GATT relay in `firmware/sailframes_edge/ble_relay.cpp`,
letting a companion app read and write the device's configurable
parameters — WiFi credentials, boat identity, recording thresholds, and
so on — without pulling the SD card, plus trigger IMU calibration.

This is **not** part of xgsail's `docs/device-protocol.md` §8 (that
document is the ingestion contract — claim, session uploads, health —
owned by the `xgsail` repo). This lives on the *same* BLE service so an
app only needs one bonded connection, but the characteristic and
commands below are firmware-specific and documented here instead.

If you're building the app-side integration, this document plus
`firmware/sailframes_edge/ble_relay.cpp` (the `device_config`
characteristic and `control`'s `calibrate`/`calibrate-reset` commands)
are the full spec.

---

## Service

Same service as the device-protocol relay:
`24e6db2c-3c8a-4b5b-ba5a-23bc4c818046`.

## Pairing window (first-time bonding)

The device's BLE bonding flag is **off by default** — a phone that
isn't already a recognized bond can still connect and read plain
characteristics, but a write to `provisioning` (`docs/device-protocol.md`
§8.2, carries `device_api_key`) or `device_config` (can carry a WiFi
password) is rejected with `{"status":"error","reason":"pairing_window_closed"}`
unless the connection is already bonded from an earlier pairing.

A long press (`button.h`, `BUTTON_LONG_PRESS_MS` in `config.h`, 2s) on the
device's physical button opens a pairing window
(`BLE_BOND_WINDOW_MS`, 60s) during which bonding is enabled and a new
phone's write to either characteristic is allowed and, on success,
persists as a bond — that phone reconnects and writes normally forever
after, with no further button presses. There's no in-band way to open
the window over BLE itself: physical access to the boat is the point.

## `control` characteristic — start/stop recording

```json
{ "cmd": "start-rec" }
```
```json
{ "cmd": "start-rec", "boat_id": "<uuid>", "activity_id": "<uuid>" }
```
```json
{ "cmd": "stop-rec" }
```

Same entry point as the physical button's short press and the console's
`rec`/`stoprec` commands (`recording.h`'s `startRecording()`/
`stopRecording()`) — recording is button/app-triggered only, there is no
GPS-speed auto-start. Neither command requires bonding (same as
`calibrate`/`calibrate-reset` below — nothing here is a secret; `boat_id`/
`activity_id` are backend record identifiers, not credentials). Notifies
back on `control`:

```json
{ "cmd": "start-rec", "ok": true, "logging": true }
```

`ok` is `false` if the command was a no-op (already recording / already
stopped, or no SD card for `start-rec`).

**`boat_id`/`activity_id` are both optional**, and independent of each
other — this is "start a session, optionally naming the boat and/or
activity it belongs to", not "pick a boat":

- Omit both (or send bare `{"cmd":"start-rec"}`) and the session gets
  the device's own boat (`device.owner_boat_id`, set at claim time) and
  a fresh private "solo" activity — today's only behavior, unchanged.
- `activity_id` — an existing XGSail activity (a race, a training
  session, ...) to fold this session into, instead of a new solo one.
  This is the field worth exposing prominently in an app's "start
  recording" flow (docs/device-protocol.md §4.4's `session-uploads`
  `activity_id` — same field, same semantics).
- `boat_id` — overrides which XGSail boat the session is filed under
  (**not** the same thing as `device_config`'s `boat_id` field, which is
  only the ESP-NOW mesh identity / log-filename prefix — see
  `docs/firmware-architecture.md`'s note on `boatIdHash()`). Only
  useful for a device that sails on more than one boat; most apps can
  leave this out entirely.

Neither value is validated by the firmware — an unrecognized UUID simply
fails the `session-uploads` call server-side once this session's files
try to upload. The device writes whichever were given to
`boat_id.txt`/`activity_id.txt` markers in the session's SD folder
(`storage.cpp`'s `startLogging()`) and echoes them back in the BLE
relay's `session_manifest` entries too (an addition beyond
`docs/device-protocol.md` §8.2's manifest shape) so an app relaying the
`session-uploads` call itself later knows what was originally intended.

## `control` characteristic — manual OTA update

```json
{ "cmd": "ota-update" }
```

Triggers an immediate firmware update check-and-apply (`docs/ota.md`),
regardless of `device_config`'s `ota_auto_update` setting. `ota-check` is
accepted as an alias. Like `start-rec`/`stop-rec`/`calibrate` above, this
doesn't require bonding — it doesn't touch persisted config, just kicks off a
check. Notifies back immediately:

```json
{ "cmd": "ota-update", "ok": true, "message": "ota update requested" }
```

`ok` is `false` only if the device refused outright — currently just
`"recording in progress"`. This ack does **not** report the update's outcome:
a successful update reboots the device, so there's nothing to notify back on
`control`. Poll the `status` characteristic's `ota` object (below) for
progress and result instead.

## `device_config` characteristic

| | |
|---|---|
| UUID | `042dfd7c-88f4-4ae8-af9a-eb1d7be7a3c6` |
| Properties | `read`, `write` (bonded + encrypted), `notify` |

**Security**: writing requires an encrypted link, and — unless this
connection is already a recognized bond from an earlier pairing —
requires the pairing window to be open (see above), same as
`provisioning` in `docs/device-protocol.md` §8.2, since a write can carry
a WiFi password. Reading is plain (no bonding required): nothing this characteristic
returns is sensitive, because **`wifi[].pass` is never included in a
read response** — it's write-only, always sent back as `""` regardless
of connection state. Set a password, but don't expect to read it back.

### Read: current configuration

**`boat_id` here is not an XGSail boat.** It's the mesh-identity/
log-filename-prefix/splash-screen label (≤15 chars, e.g. `"E1"`) —
`config.txt`'s `boat_id`, hashed into the ESP-NOW sender id
(`docs/firmware-architecture.md`). The XGSail boat a session uploads
under is `device.owner_boat_id` (set once, at claim time, server-side —
not writable here) unless overridden per-session via `control`'s
`start-rec` `boat_id` above. An app UI editing this field should label
it something like "device name on the mesh", not "boat", to avoid
implying it changes which XGSail boat the device's data belongs to.

```json
{
  "boat_id": "E1",
  "unit_role": "racing_boat",
  "api_base_url": "https://xgsail.example.com",
  "wind_mac": "AA:BB:CC:DD:EE:FF",
  "wind_offset": 0,
  "start_speed_knots": 1.5,
  "stop_speed_knots": 0.5,
  "start_delay_sec": 10,
  "stop_delay_sec": 180,
  "rtk_enabled": false,
  "auto_cleanup_uploads": true,
  "ota_auto_update": false,
  "ota_base_url": "https://xgsail.com/ota",
  "display_mode": 2,
  "wifi": [
    { "ssid": "YourHomeNetwork", "pass": "" },
    { "ssid": "YachtClubNetwork", "pass": "" }
  ]
}
```

### Write: partial update

Only the keys you include are changed — omit anything you don't want to
touch. `wifi`, if present, **replaces the entire array** (not a
per-slot merge): send every network you want kept, up to 5.

```json
{
  "wifi": [
    { "ssid": "NewHomeNetwork", "pass": "newpassword" }
  ],
  "boat_id": "E7",
  "start_speed_knots": 2.0
}
```

Response, notified back on the same characteristic:

```json
{ "status": "ok" }
```

or, on failure:

```json
{ "status": "error", "reason": "bad_json" }
```

(`reason` is one of `pairing_window_closed` — this connection isn't
already bonded and no long-press has opened the pairing window (see
above) — `bad_json` — the write body didn't parse as JSON — or
`sd_busy` — the SD card was in use by the recording/upload path at
the moment of the write; safe to retry).

### Field reference and live-apply behavior

Every field below takes effect **immediately, without a reboot** — that
was a deliberate design goal, not a limitation to work around. How each
one applies:

| Field | Type | Applies |
|---|---|---|
| `wifi` | array of `{ssid, pass}`, ≤5 | Immediately — the next connection attempt reads it fresh. |
| `api_base_url` | string | Immediately — the next device-protocol API call reads it fresh. |
| `boat_id` | string, ≤15 chars | Immediately — also recomputes the ESP-NOW mesh identity, so the boat doesn't keep broadcasting under its old name. |
| `unit_role` | string: `racing_boat`, `rc_signal`, `rc_pin`, `mark`, `committee_chase`, `spare` | Immediately. |
| `wind_mac` | string, Calypso MAC (`AA:BB:CC:DD:EE:FF`) or `""` | Immediately — an empty string disables the wind sensor; any other value enables it and forces a reconnect to the new device on the next cycle. |
| `wind_offset` | int, degrees | Immediately. |
| `start_speed_knots` | float, knots | Immediately — but only fed into upload.cpp's "boat is moving, don't upload right now" check. Recording itself is button/console/BLE-triggered (`control`'s `start-rec`/`stop-rec` above), not speed-triggered. |
| `stop_speed_knots` / `start_delay_sec` / `stop_delay_sec` | float / int / int | Round-tripped for older cards' `config.txt` compatibility — **unused by the firmware**. Don't build UI around them. |
| `rtk_enabled` | bool | Immediately — reconfigures the GNSS module (base/rover RTK) right away, the same live path the console's `gpscfg` command already uses. |
| `auto_cleanup_uploads` | bool | Immediately — the next successful upload (WiFi or BLE relay) reads it fresh before deciding whether to delete the file. Default `true`. |
| `ota_auto_update` | bool | Persisted opt-in for automatic OTA firmware update checks (`docs/ota.md`). Default `false`. A manual update can still be triggered with `control`'s `ota-update` (above) even when this is off. Never runs while recording either way. |
| `ota_base_url` | string, URL | Persisted. Base URL of the OTA firmware feed (`<url>/manifest.json`). Default `https://xgsail.com/ota` — only override for staging/self-hosted. Read fresh on the next OTA check. |
| `display_mode` | int, `1`\|`2`\|`3` | Immediately — same effect as cycling the console's `display` command: `1` = D1 (simple, large numbers), `2` = D2 (Vakaros-style nav + wind, default), `3` = D3 (wind focus). Out-of-range values are ignored (rest of the write still applies). Persisted, so it survives a reboot. |

**Not configurable here, and why:**
- `claim_code` — irrelevant to this characteristic. BLE claiming already
  happens through `provisioning` (`docs/device-protocol.md` §8.3): the
  app calls `claim/confirm` itself and relays the resulting
  `device_api_key` directly, so there's never a raw claim code for the
  device to consume over BLE.
- `hardware_platform` — fixed to `"e1"` in this firmware; not a real
  setting.

### Persistence and `config.txt`

Every write rewrites `/config.txt` in full, from the device's current
in-memory configuration. This keeps the SD card consistent with
whatever was last set over BLE (or by hand before the first BLE write),
but **any hand-written comments or custom formatting in `config.txt` are
lost the first time a BLE write happens** — the file that comes back out
is plain `key=value` lines, nothing else. If you rely on a heavily
annotated `config.txt`, keep your own copy of it; the device will no
longer preserve one.

---

## `control` characteristic — calibration commands

Two additional commands on the existing `control` characteristic
(`ec88dd3e-2562-420c-aebe-30a4ae40bdf9`, `docs/device-protocol.md` §8.2),
alongside its documented `start-transfer`/`ack-uploaded`. `control` now
also has `notify` (an addition beyond §8.2 — purely additive, a client
that never subscribes sees no difference for the two existing commands).

```json
{ "cmd": "calibrate" }
```

Zeroes heel/pitch at the boat's **current** attitude — same as the
console's `cal` command. Only meaningful with the boat sitting level;
the app is responsible for telling the user to do that first.

```json
{ "cmd": "calibrate-reset" }
```

Resets heel/pitch offsets back to zero (undoes any prior calibration) —
same as the console's `calreset` command.

Both notify a status back on `control`:

```json
{ "cmd": "calibrate", "status": "ok", "heel_offset": 2.3, "pitch_offset": -0.5 }
```

```json
{ "cmd": "calibrate", "status": "error", "reason": "no_imu" }
```

(`reason` is `no_imu` — the BNO085 wasn't detected at boot — or
`sd_busy`, safe to retry.)

---

## `status` characteristic (read-only)

Live runtime state — distinct from `device_config` (how the device is
*set up*) and `identity` (its stable identity). Read on demand; there is
no periodic push. Same fields the console's `status` command already
prints, just as JSON instead of a serial dump — nothing here is
computed specially for BLE.

| | |
|---|---|
| UUID | `bfef7865-f3f7-486c-93fe-bbae78cfdc43` |
| Properties | `read` only — no write, no notify |

No bonding required: nothing in the payload is a secret (your own
boat's GPS position and WiFi SSID, not a password).

```json
{
  "claimed": true,
  "firmware_version": "2026.06.29.02",
  "uptime_s": 5423,
  "heap_free": 142300,
  "battery": { "pct": 78, "v": 3.91, "critical": false },
  "sd_ok": true,
  "wifi": { "connected": true, "ssid": "YachtClub", "ip": "192.168.1.42" },
  "sensors": { "imu": true, "pressure": true, "wind": true },
  "gps": { "fix": true, "satellites": 9, "hdop": 1.2, "lat": 42.36012, "lon": -71.05821, "speed_kts": 5.2, "course": 210 },
  "wind": { "connected": true, "speed_kts": 12.1, "angle_deg": 45, "battery": 88 },
  "recording": { "logging": true, "session_count": 3, "pending_uploads": 1, "elapsed_s": 842 },
  "ota": { "state": "downloading", "progress": 42 }
}
```

Field notes:
- `firmware_version` — the running build, `YYYY.MM.DD.N` (date + daily
  build number). Always present. It's the basis for OTA's "is a newer build
  available?" decision (`docs/ota.md`), and the same value the device reports
  to the backend in its health snapshot.
- `ota` — state of the last automatic or manual (`control`'s `ota-update`)
  update check (`docs/ota.md`). `state` is one of `idle` / `checking` /
  `up_to_date` / `downloading` / `applying` / `suspended` / `error`.
  `progress` (0-100) is only present while `downloading`. `message` is a
  short detail, present on `error`/`suspended`.
- `wifi.ssid`/`wifi.ip` are only present when `wifi.connected` is `true`.
- `sensors` reports **presence**, not live readings — whether the IMU/
  pressure chip were detected at boot, and whether a wind sensor is
  currently paired (`config.wind_enabled`). Wind's live reading is the
  separate `wind` object below.
- `gps.fix` is `false` and the rest of `gps` is stale/zeroed until the
  GNSS module gets its first fix.
- `wind.speed_kts`/`wind.angle_deg`/`wind.battery` are only present when
  `wind.connected` is `true` (no wind sensor paired, or not currently
  connected, means just `{"connected": false}`).
- `recording.pending_uploads` counts sessions with files still to
  upload, over WiFi or BLE relay — same count the `status` console
  command and the device's own display show.
- `recording.elapsed_s` — seconds since the current session started
  (`storage.cpp`'s `logStart`). Only present while `logging` is `true`;
  omitted rather than stale when not recording.

## Concurrency note (for firmware maintainers, not app authors)

Every SD-card access reachable from a BLE callback — `device_config`'s
read/write, `control`'s calibration commands, and the existing
`provisioning`/`session_manifest`/`session_data` handlers — takes the
firmware's `sdMutex` (skip-if-busy, not a hard block) before touching the
SD card. BLE callbacks run on the NimBLE host's own FreeRTOS task, a
third execution context distinct from Core 1's sensor/display loop and
Core 0's upload task; without this, a BLE-triggered write could race
against either. See `ble_relay.cpp`'s `BLE_SD_MUTEX_TIMEOUT` and its
usages for the exact pattern. `status` is the one exception — it only
reads already-maintained in-memory globals, never the SD card, so its
`onRead` doesn't take `sdMutex`.

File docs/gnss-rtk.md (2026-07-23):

# GNSS / RTK reference

How E1 configures and uses its GNSS module (Waveshare LG290P), and how
its real-time-kinematic (RTK) correction relay actually works today. All
commands and behavior below are taken from `firmware/sailframes_edge/
gnss.cpp` and `rtk_relay.{h,cpp}` — this is what the shipped firmware
does, not a design proposal.

## Module and wiring

- **Waveshare LG290P** GNSS receiver, ESP32 UART2 at 460800 baud
  (`GPS_RX_PIN`/`GPS_TX_PIN` = GPIO16/17, `GPS_BAUD` in `config.h`).
- Configuration happens entirely over that UART using **PQTM** commands
  (`sendPQTM()` in `gnss.cpp` appends the NMEA-style checksum and reads
  back the module's response).

## Rover configuration (the default, RTK off)

`configureLG290P()` runs at boot and on the `gpscfg` console command. It:

1. Queries firmware version (`PQTMVERNO`, for `/boot.log` forensics).
2. Sets **Rover mode** — `PQTMCFGRCVRMODE,W,1` — required to unlock the
   10 Hz fix rate (Base mode locks the module to 1 Hz).
3. Enables GGA/RMC/GSA/GSV NMEA sentences at the current rate
   (`PQTMCFGMSGRATE,W,<sentence>,1` for each).
4. Sets the fix rate to 10 Hz — `PQTMCFGFIXRATE,W,100` (100 ms) —
   *before* the save+restart below, so the new rate is in NVM and applied
   by the same-boot restart.
5. Saves to NVM and restarts the module (`PQTMSAVEPAR` then `PQTMSRR`,
   ~6 s wait), then reads back `PQTMCFGRCVRMODE,R` / `PQTMCFGFIXRATE,R`
   to confirm.

This NMEA-only path was the entire GNSS config for a long time (see "PPK
capture — retired" below for what used to run alongside it). It is
**byte-identical** whether or not RTK is compiled in — `gnssConfigure()`
falls straight through to `configureLG290P()` when `config.rtk_enabled`
is false, which is the default.

## RTK relative mode

When `config.rtk_enabled` is true, `gnssConfigure()` instead calls one of
two role-specific configurators:

- **Rover** (`lg290pConfigRover()`): runs `configureLG290P()` unchanged,
  then enables RTK relative mode — `PQTMCFGRTK,W,1,2,120` (auto diff
  mode, relative mode, 120 s max correction age) — and turns on the
  accuracy-output sentence: `PQTMCFGMSGRATE,W,GST,1`. GST gives
  1-sigma lat/lon/alt error in metres; `parseNMEA()` combines
  `sqrt(lat_std² + lon_std²)` into `gps.hacc_m`, the single
  "how accurate is this fix" number the rest of the firmware reads (mesh
  broadcast, RC panels, nav display).
- **Base** (`lg290pConfigBase()`, used by the `rc_signal` role): sets
  Base mode (`PQTMCFGRCVRMODE,W,2`, locks 1 Hz), a short/loose survey-in
  (`PQTMCFGSVIN,W,1,60,0,0,0,0`), saves + restarts, then — **every
  boot, never saved** — requests RTCM3 output:
  `PQTMCFGRTCM,W,7,0,-90,07,06,1,0` (MSM7 requested, elevation mask off,
  GPS+GLONASS+Galileo, L1+L2, ephemeris on-update). **The module actually
  emits MSM4** (1074/1084/1094/1124) even though MSM7 was requested —
  this is a known LG290P firmware quirk, not a bug in this configuration;
  MSM4 is sufficient for centimeter-level positioning. Because this
  command doesn't persist, it's resent on every boot rather than saved —
  do not add a `PQTMSAVEPAR`/`PQTMSRR` after it. Base mode also
  auto-disables NMEA, so GGA/RMC/GSA/GST are re-enabled after the RTCM3
  command so the RC unit still gets its own position/HDOP for the
  pre-race panel.

## RTK correction relay (ESP-NOW, not a cable)

There's no direct RTK radio link between boats — corrections ride the
same ESP-NOW mesh used for boat-state broadcasts (see
`docs/firmware-architecture.md`):

- **Base** (`readGPSBase()`, `rtk_relay.h`'s `RtcmFramer`): demuxes the
  Base's UART stream — length-driven, not `$`-keyed, since a `0x24` byte
  can appear inside a binary RTCM3 payload — into complete, CRC-24Q
  validated frames. Each valid frame is handed to
  `rtcmBroadcastFrame()`, which splits it into up to 5 fragments
  (`RTCM_FRAG_MAX` = 230 B, capped by the 250 B ESP-NOW packet limit) and
  sends each one twice for loss margin.
- **Rover** (`RtcmReassembler` in `rtk_relay.h`): reassembles fragments
  by `msg_id`, with a two-level dedup (in-flight `got_mask` per fragment
  index, plus a `last_done_msg_id` guard against the base's own 2×
  retransmission). A complete, CRC-valid frame goes into a small
  FreeRTOS stream-buffer ring (`g_rtcmRing`) — the only object that
  crosses the ESP-NOW receive-callback / main-loop boundary — and
  `loop()` drains it straight to the GNSS UART a few bytes at a time,
  non-blocking.
- Both directions are gated off during an active upload (`wifiBusy` /
  `uploading`) to avoid RF contention with HTTP traffic — a lesson from
  earlier fleet hangs, not a design choice made lightly (see the "gotcha"
  comments in `mesh.cpp`/`rtk_relay.cpp` for the specific incidents).

RTK is **off by default** (`config.rtk_enabled = false`) and is SD-config
only — deliberately not part of the cloud config allow-list, since
flipping it reconfigures the GNSS module, a physical bring-up act rather
than something safe to push remotely.

## PPK post-processing — retired, kept for history

An earlier firmware generation logged raw RTCM3 to the SD card
(`*_raw.rtcm3` per session) for **offline** post-processed kinematic
(PPK) positioning: upload the file, pull the matching hour(s) of RINEX
observations from a CORS base station, and run RTKLIB's `rnx2rtkp`
locally for centimeter-level positions after the fact. That capture path
was retired in firmware `2026.05.20.09` in favor of the live RTK relay
above — 10 Hz real-time fixes matter more for on-the-water OCS detection
than decimeter-accurate positions available only after the race.

If you ever resurrect offline PPK from archived `.rtcm3` files, the one
non-obvious pitfall worth knowing about: matching RINEX 2 (from most CORS
stations) against RINEX 3 (from `convbin`/RTKCONV's own RTCM3 conversion)
observation codes isn't automatic in stock RTKLIB. RINEX 2's plain `C2`/
`L2` (P(Y)-code) doesn't get matched against RINEX 3's `C2X`/`L2X`
(L2C civilian) even when both sides are tracking compatible dual-frequency
signals, which silently drops dual-frequency observations and produces a
0% fix rate that looks like a signal-compatibility problem but isn't. The
[RTKExplorer demo5 fork](https://github.com/rtklibexplorer/RTKLIB) handles
mixed-version code matching; on stock RTKLIB, set `pos1-frequency=l1+l2`
and an explicit code priority (`pos1-codepri_gps_l2=XSLWPYMCQ`, preferring
L2C over P(Y)) in `ppk.conf`.

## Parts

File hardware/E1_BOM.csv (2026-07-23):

Category | Component | Description | Part Number | Qty Per Unit | Qty for 5 Units | Unit Price USD | Total USD | Source | Link/Notes
Main | ESP32 DevKit V1 | ELEGOO ESP32 DevKit V1 CP2102 USB-C | ELEGOO-ESP32 | 1 | 5 | 7.00 | 35.00 | Amazon | 3-pack available ~$20
Main | GPS Module | Waveshare LG290P GNSS quad-band PPK-capable with antenna | LG290P | 1 | 5 | 109.00 | 545.00 | Waveshare | waveshare.com direct
Main | IMU | GY-BNO08X BNO085 9DOF AHRS breakout | GY-BNO08X | 1 | 5 | 15.00 | 75.00 | Amazon/AliExpress | I2C address 0x4A
Main | TFT Display | Hosyond 3.5 inch IPS TFT ST7796U 480x320 SPI | ST7796U-3.5 | 1 | 5 | 15.00 | 75.00 | Amazon | White background sunlight readable
Main | SD Card Module | MicroSD card breakout module SPI | SD-SPI | 1 | 5 | 2.00 | 10.00 | Amazon | 6-pin SPI interface
Main | SD Card | 16GB microSD card | SD-16GB | 1 | 5 | 5.00 | 25.00 | Amazon | FAT32 formatted
Main | Boost Charger | DWEII USB-C 5V 2A Boost Converter with LiPo charging | DWEII-5V2A | 1 | 5 | 1.25 | 6.25 | Amazon | 10-pack available ~$12
Main | Battery | 906090 3.7V 6000mAh LiPo with JST PH 2.0mm connector | 906090-6000 | 1 | 5 | 13.00 | 65.00 | Amazon | Check polarity before connecting
Main | PCB | E1 v1.0 PCB 60.5x91.5mm 2-layer | PCB-E1-V1 | 1 | 5 | 2.00 | 10.00 | JLCPCB | Order 10 minimum ~$10 total
Connectors | Pin Headers 40-pin | 2.54mm male pin header strip | PH-40M | 2 | 10 | 0.25 | 2.50 | Amazon | Cut to size as needed
Connectors | JST PH Socket | JST PH 2.0mm 2-pin through-hole socket | JST-PH-2 | 1 | 5 | 0.20 | 1.00 | Amazon/DigiKey | For battery connector J10
Connectors | Power Switch | SPDT slide switch SS12D10-G5 5mm pitch | SS12D10 | 1 | 5 | 0.30 | 1.50 | Amazon | 3-pin through-hole
SMD | Resistor 100K | 100K ohm 0805 SMD resistor | R-100K-0805 | 2 | 10 | 0.02 | 0.20 | DigiKey/LCSC | Voltage divider R1 R2
SMD | Resistor 4.7K | 4.7K ohm 0805 SMD resistor | R-4K7-0805 | 2 | 10 | 0.02 | 0.20 | DigiKey/LCSC | I2C pull-ups R3 R4
Enclosure | Enclosure | YETLEBOX IP67 ABS 5.9x3.9x2.8 inch clear lid | YETLEBOX-IP67 | 1 | 5 | 15.00 | 75.00 | Amazon | Clear lid for display visibility
Enclosure | Standoffs M3 | M3 nylon standoff assortment kit | M3-STANDOFF | 1 | 1 | 10.00 | 10.00 | Amazon | Shared kit for all units
Enclosure | Screws M3 | M3 stainless steel screw assortment | M3-SCREWS | 1 | 1 | 8.00 | 8.00 | Amazon | Shared kit for all units
Optional | Pressure Sensor | Adafruit DPS310 I2C pressure sensor | DPS310 | 1 | 5 | 10.00 | 50.00 | Adafruit | Future - barometric data
Optional | Wind Sensor Board | Custom wind sensor MCU board | WIND-MCU | 1 | 5 | 0.00 | 0.00 | TBD | Future - UART1 expansion ready
Summary |  |  |  |  | Total Main Components |  |  | 837.25
Summary |  |  |  |  | Total Connectors |  |  | 5.00
Summary |  |  |  |  | Total SMD |  |  | 0.40
Summary |  |  |  |  | Total Enclosure |  |  | 93.00
Summary |  |  |  |  | GRAND TOTAL |  |  | 935.65
Summary |  |  |  |  | Cost Per Unit |  |  | 187.13

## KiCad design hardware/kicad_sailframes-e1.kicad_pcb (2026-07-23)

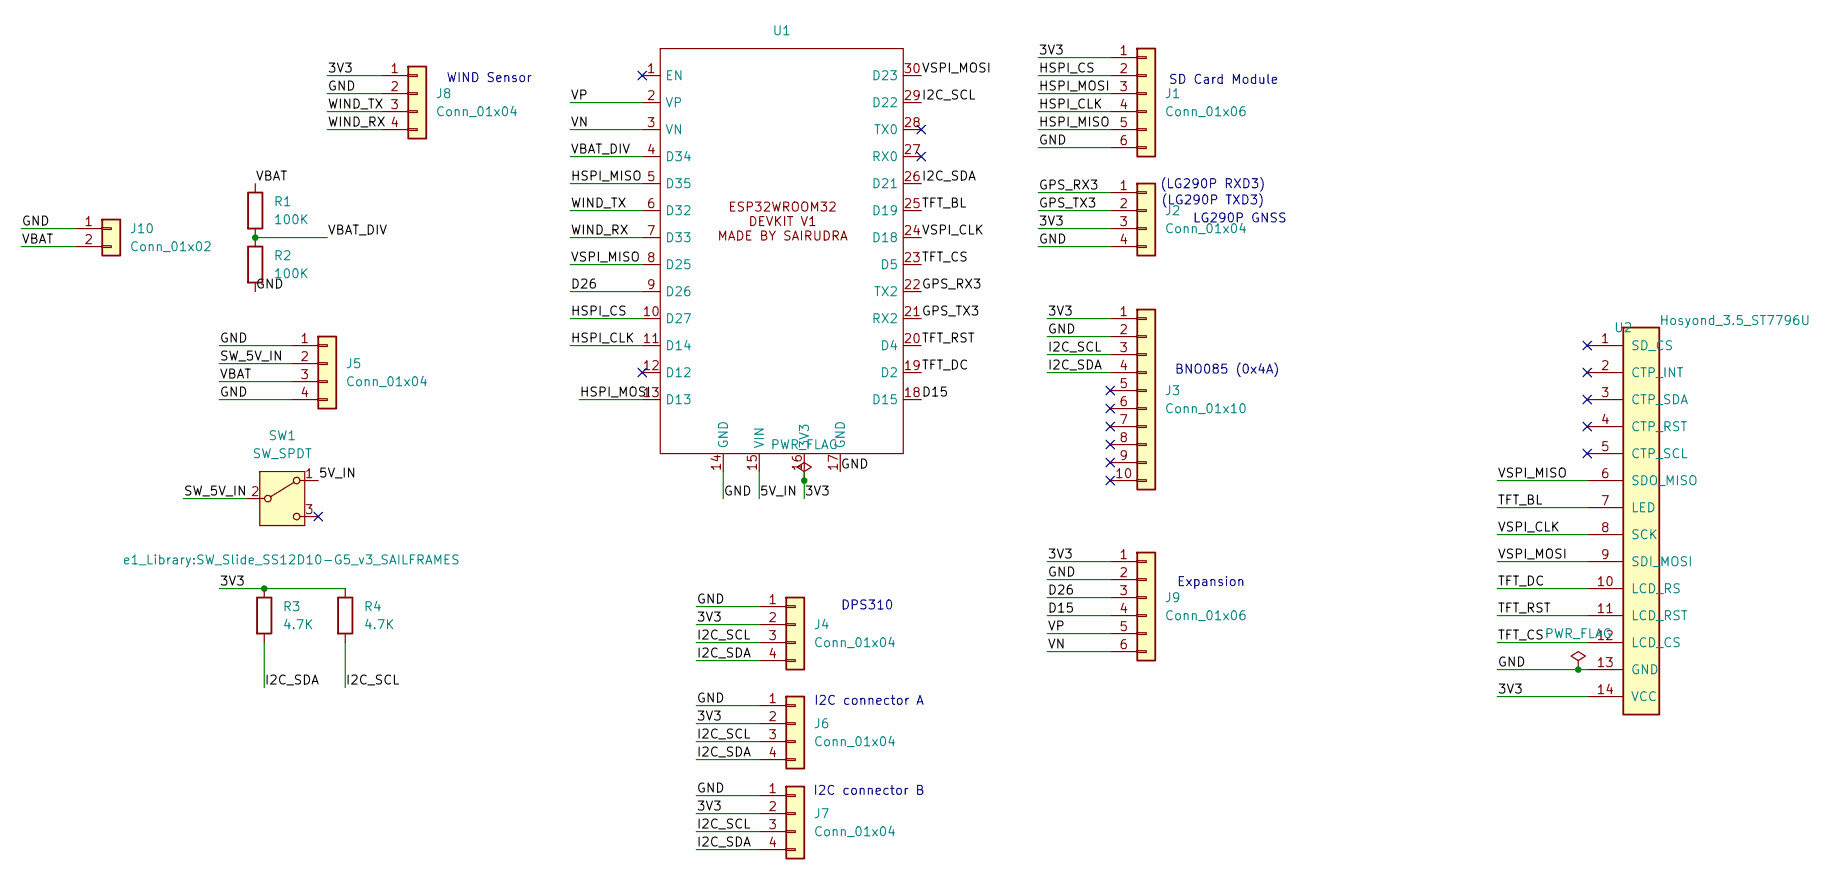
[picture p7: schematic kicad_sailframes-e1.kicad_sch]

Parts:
J1: Conn_01x06; SD_CARD
J2, J4, J5, J6, J7, J8: Conn_01x04; PinHeader_1x04_P2.54mm_Vertical
J3: Conn_01x10; PinHeader_1x10_P2.54mm_Vertical
J9: Conn_01x06; PinHeader_1x06_P2.54mm_Vertical
J10: Conn_01x02; JST_PH_S2B-PH-K_1x02_P2.00mm_Horizontal
R1, R2: 100K; R_0805_2012Metric
R3, R4: 4.7K; R_0805_2012Metric
SW1: SW_SPDT; SW_Slide_SS12D10-G5_v3_SAILFRAMES
U1: ESP32DEVIKITV1
U2: Hosyond_3.5_ST7796U; PinHeader_1x14_P2.54mm_Vertical

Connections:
/3V3: J1.1, J2.3, J3.1, J4.2, J6.2, J7.2, J8.1, J9.1, R3.1, R4.1, U1.16 (3V3), U2.14 (VCC)
/5V_IN: SW1.1 (A), U1.15 (VIN)
/D15: J9.4, U1.18 (D15)
/D26: J9.3, U1.9 (D26)
/GND: J1.6, J2.4, J3.2, J4.1, J5.1, J5.4, J6.1, J7.1, J8.2, J9.2, J10.1, R2.2, U1.14 (GND), U1.17 (GND), U2.13 (GND)
/GPS_RX3: J2.1, U1.22 (TX2)
/GPS_TX3: J2.2, U1.21 (RX2)
/HSPI_CLK: J1.4, U1.11 (D14)
/HSPI_CS: J1.2, U1.10 (D27)
/HSPI_MISO: J1.5, U1.5 (D35)
/HSPI_MOSI: J1.3, U1.13 (D13)
/I2C_SCL: J3.3, J4.3, J6.3, J7.3, R4.2, U1.29 (D22)
/I2C_SDA: J3.4, J4.4, J6.4, J7.4, R3.2, U1.26 (D21)
/SW_5V_IN: J5.2, SW1.2 (B)
/TFT_BL: U1.25 (D19), U2.7 (LED)
/TFT_CS: U1.23 (D5), U2.12 (LCD_CS)
/TFT_DC: U1.19 (D2), U2.10 (LCD_RS)
/TFT_RST: U1.20 (D4), U2.11 (LCD_RST)
/VBAT: J5.3, J10.2, R1.1
/VBAT_DIV: R1.2, R2.1, U1.4 (D34)
/VN: J9.6, U1.3 (VN)
/VP: J9.5, U1.2 (VP)
/VSPI_CLK: U1.24 (D18), U2.8 (SCK)
/VSPI_MISO: U1.8 (D25), U2.6 (SDO_MISO)
/VSPI_MOSI: U1.30 (D23), U2.9 (SDI_MOSI)
/WIND_RX: J8.4, U1.7 (D33)
/WIND_TX: J8.3, U1.6 (D32)

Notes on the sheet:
Expansion
LG290P GNSS
(LG290P RXD3)
(LG290P TXD3)
SD Card Module
BNO085 (0x4A)
WIND Sensor
I2C connector A
DPS310
I2C connector B

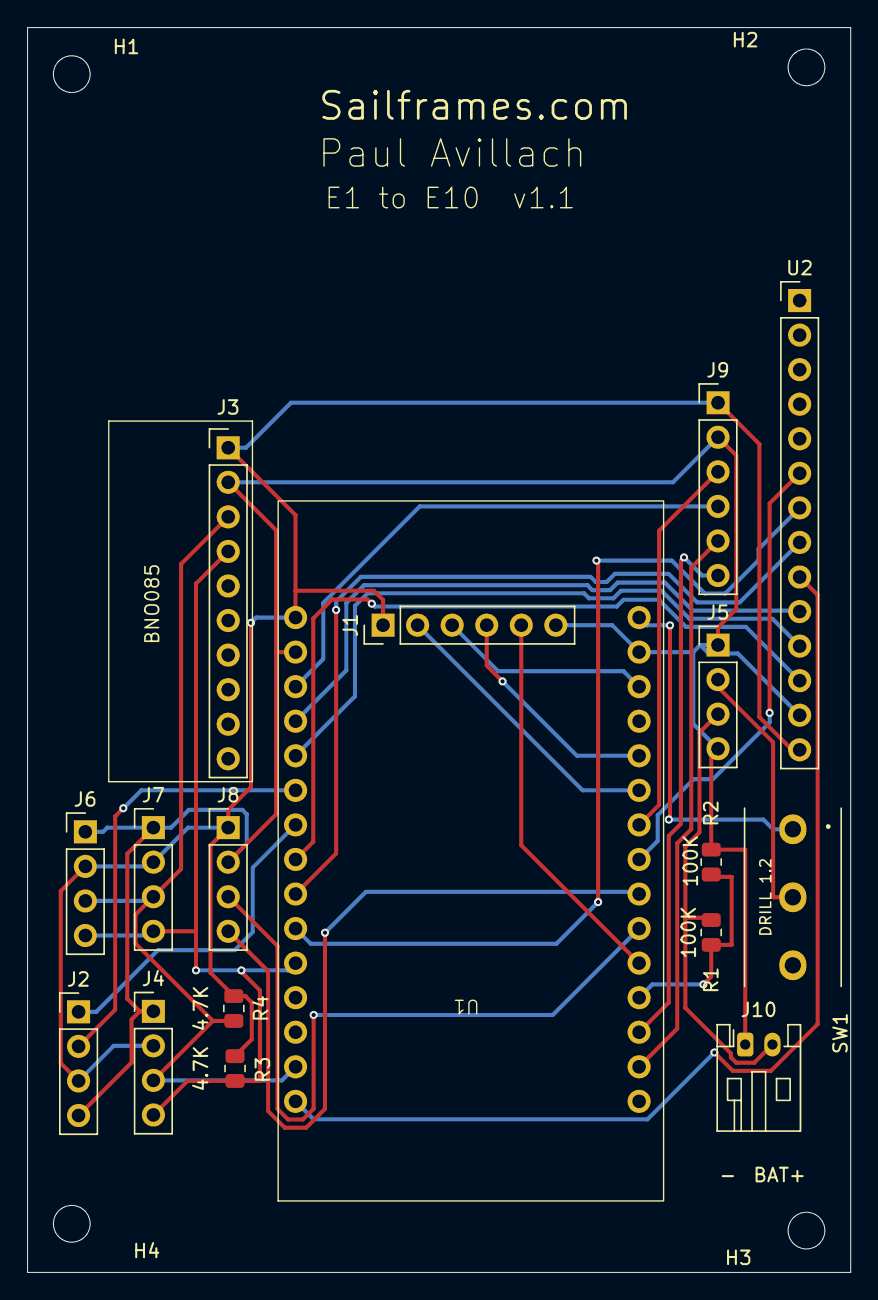
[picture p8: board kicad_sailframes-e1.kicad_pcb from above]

Board: 2 copper layers, 60.5 x 91.5 mm, 21 parts (0 on the bottom side), 27 nets.

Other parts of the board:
H1, H2, H3, H4: MountingHole_2.7mm_M2.5

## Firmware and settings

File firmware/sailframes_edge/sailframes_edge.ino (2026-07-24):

/*
 * SailFrames E1 — Fleet Tracker Firmware
 *
 * Hardware:
 *   - ESP32 DevKit V1 (ELEGOO)
 *   - Waveshare LG290P GNSS (UART2: RX=GPIO16, TX=GPIO17, 460800 baud)
 *   - BNO085 IMU (I2C: 0x4A) — heel, pitch, heading
 *   - DPS310 Pressure/Temp (I2C: 0x77) — barometric pressure for gust detection
 *   - Hosyond 3.5" IPS ST7796U TFT 480x320 (SPI: CS=5, DC=2, RST=4, BL=25)
 *   - MicroSD standalone module (SPI shared: MOSI=23, MISO=19, CLK=18, CS=27)
 *   - Calypso Mini wind sensor (BLE) — apparent wind speed/direction
 *   - DWEII USB-C 5V Boost Converter + LiPo cell
 *   - 100K/100K voltage divider on GPIO34 for battery monitoring
 *
 * Behavior:
 *   Power on → init sensors → configure LG290P (Rover mode, 10 Hz NMEA)
 *   → scan for Calypso wind sensor (BLE) → wait for GPS fix
 *   → auto-log to SD (NMEA CSV + IMU CSV + Wind CSV + Pres CSV)
 *   → when yacht club Wi-Fi detected → auto-upload to AWS S3
 *   Power off → done
 *
 * NOTE: PPK / raw-RTCM3 capture was retired in firmware 2026.05.20.09.
 * See docs/gnss-rtk.md for the previous architecture.
 *
 * Log files per session:
 *   /sf/YYYYMMDD/E1_YYYYMMDD_HHMMSS_nav.csv  (10 Hz)
 *   /sf/YYYYMMDD/E1_YYYYMMDD_HHMMSS_imu.csv  (10 Hz)
 *   /sf/YYYYMMDD/E1_YYYYMMDD_HHMMSS_wind.csv (1 Hz when Calypso paired)
 *   /sf/YYYYMMDD/E1_YYYYMMDD_HHMMSS_pres.csv (0.1 Hz, DPS310 only)
 *
 * License: Apache 2.0
 *
 * This file is the composition root: global object wiring, setup(), and
 * loop(). Everything else lives in the per-responsibility modules listed
 * below (see CLAUDE.md "Repository Structure").
 */

#include <Wire.h>
#include <SPI.h>
#include <SD.h>
#include <WiFi.h>
#include <WiFiClient.h>
#include <WiFiClientSecure.h>
#include <HTTPClient.h>
#include <Adafruit_BNO08x.h>
#include <Adafruit_DPS310.h>
#include <esp_heap_caps.h>
#include <esp_task_wdt.h>
// NimBLE configuration. CENTRAL+OBSERVER: the existing Calypso wind-sensor
// client (wind_sensor.cpp). PERIPHERAL: the device-protocol GATT relay
// server (ble_relay.cpp) — connectable advertising + accepting the phone
// app's connection, run concurrently with the central role. 2 connections/
// bonds: one outbound (wind sensor, unbonded) + one inbound (phone relay,
// bonded for the `provisioning` characteristic).
#define CONFIG_BT_NIMBLE_ROLE_CENTRAL 1
#define CONFIG_BT_NIMBLE_ROLE_PERIPHERAL 1
#define CONFIG_BT_NIMBLE_ROLE_OBSERVER 1
#define CONFIG_BT_NIMBLE_ROLE_BROADCASTER 0
#define CONFIG_BT_NIMBLE_MAX_CONNECTIONS 2
#define CONFIG_BT_NIMBLE_MAX_BONDS 2
#define CONFIG_BT_NIMBLE_SVC_GAP_DEVICE_NAME "SailFrames-E1"
#include <NimBLEDevice.h>
#include <esp_now.h>
#include <esp_wifi.h>
#include <string>

#include "config.h"
#include "v2_types.h"
#include "mesh.h"
#include "rtk_relay.h"
#include "gnss.h"
#include "imu.h"
#include "wind_sensor.h"
#include "pressure.h"
#include "battery.h"
#include "recording.h"
#include "button.h"
#include "ocs.h"
#include "display.h"
#include "storage.h"
#include "telnet.h"
#include "console.h"
#include "device_auth.h"
#include "ble_relay.h"
#include "upload.h"
#include "shared_state.h"

void setup() {
  Serial.begin(SERIAL_BAUD);
  delay(500);

  // Capture WHY we last rebooted before any other init runs. The fleet
  // had a simultaneous-reboot event on 2026-05-03 with no serial captured;
  // this prints the cause at the top of the next boot log AND appends it
  // to /boot.log on SD so we can read it later if no USB was connected.
  esp_reset_reason_t resetReason = esp_reset_reason();

  Serial.println("\n=================================");
  Serial.printf("  SailFrames Edge %s\n", FW_VERSION);
  Serial.println("  Hardware Power Switch Edition");
  Serial.printf("  Reset reason: %s (%d)\n", resetReasonStr(resetReason), (int)resetReason);
  Serial.printf("  Free heap: %u, min ever: %u\n",
                ESP.getFreeHeap(),
                (unsigned)esp_get_minimum_free_heap_size());
  Serial.println("=================================");

  // Create SD mutex for dual-core safety
  sdMutex = xSemaphoreCreateMutex();
  if (sdMutex == NULL) {
    Serial.println("[ERR] Failed to create SD mutex!");
  }

  // Initialize WiFi FIRST before any peripherals touch GPIO2
  // This must happen before Wire, SPI, or any other peripheral init
  pinMode(2, INPUT);  // Release GPIO2
  WiFi.mode(WIFI_STA);
  WiFi.disconnect(true);
  delay(100);
  Serial.println("[WIFI] PHY initialized early");

  if (LED_PIN >= 0) pinMode(LED_PIN, OUTPUT);

  // Battery monitoring (PowerBoost 1000C)
  setupBattery();
  updateBattery();  // Initial reading
  Serial.printf("[BATT] Initial: %.2fV (%d%%)\n", battery.voltage, battery.percent);
  if (battery.critical) {
    Serial.println("[BATT] WARNING: Battery critical on startup!");
  }

  Wire.begin(SDA_PIN, SCL_PIN);
  Wire.setBufferSize(512);  // BNO085 SHTP needs larger buffer
  Wire.setClock(100000);  // Start slow for reliable init
  delay(100);  // Let I2C bus stabilize

  // BNO085 needs up to 1 second to boot after power-on
  Serial.println("[I2C] Waiting for BNO085 boot (1s)...");
  delay(1000);

  // I2C Scanner - check all addresses to debug
  Serial.println("[I2C] Scanning bus...");
  for (uint8_t addr = 0x08; addr < 0x78; addr++) {
    Wire.beginTransmission(addr);
    if (Wire.endTransmission() == 0) {
      Serial.printf("[I2C] Found device at 0x%02X\n", addr);
    }
  }

  // Check expected devices
  Serial.println("[I2C] Checking expected devices...");
  Wire.beginTransmission(BNO085_ADDR);
  bool bnoFound = (Wire.endTransmission() == 0);
  Wire.beginTransmission(DPS310_ADDR);
  bool dpsFound = (Wire.endTransmission() == 0);
  Serial.printf("[I2C] BNO085 0x4B: %s\n", bnoFound ? "YES" : "NO");
  Serial.printf("[I2C] DPS310 0x77: %s\n", dpsFound ? "YES" : "NO");

  // IMU — BNO085 (init early, before SPI peripherals)
  Serial.println("[IMU] Initializing BNO085...");
  bool imuInitOK = bno08x.begin_I2C(BNO085_ADDR, &Wire);

  if (imuInitOK) {
    imuOK = true;
    Wire.setClock(400000);  // Switch to fast mode after init
    Serial.println("[IMU] BNO085 detected, enabling reports");
    if (!bno08x.enableReport(SH2_GAME_ROTATION_VECTOR, IMU_INTERVAL_MS * 1000)) {
      Serial.println("[IMU] WARNING: Failed to enable game rotation vector");
    }
    if (!bno08x.enableReport(SH2_ROTATION_VECTOR, IMU_INTERVAL_MS * 1000)) {
      Serial.println("[IMU] WARNING: Failed to enable rotation vector");
    }
    if (!bno08x.enableReport(SH2_ACCELEROMETER, IMU_INTERVAL_MS * 1000)) {
      Serial.println("[IMU] WARNING: Failed to enable accelerometer");
    }
    if (!bno08x.enableReport(SH2_GYROSCOPE_CALIBRATED, IMU_INTERVAL_MS * 1000)) {
      Serial.println("[IMU] WARNING: Failed to enable gyroscope");
    }
    if (!bno08x.enableReport(SH2_LINEAR_ACCELERATION, IMU_INTERVAL_MS * 1000)) {
      Serial.println("[IMU] WARNING: Failed to enable linear acceleration");
    }
    if (!bno08x.enableReport(SH2_STABILITY_CLASSIFIER, 500000)) {
      Serial.println("[IMU] WARNING: Failed to enable stability classifier");
    }
    if (!bno08x.enableReport(SH2_MAGNETIC_FIELD_CALIBRATED, IMU_INTERVAL_MS * 1000)) {
      Serial.println("[IMU] WARNING: Failed to enable magnetometer");
    }
    Serial.println("[IMU] BNO085 OK");
  } else {
    Serial.println("[IMU] BNO085 not found!");
  }

  // Set up CS pins before any SPI init
  pinMode(TFT_CS_PIN, OUTPUT);
  digitalWrite(TFT_CS_PIN, HIGH);
  pinMode(SD_CS_PIN, OUTPUT);
  digitalWrite(SD_CS_PIN, HIGH);
  delay(100);

  // SD Card - Initialize on HSPI bus (separate from TFT's VSPI)
  Serial.println("[SD] Initializing on HSPI bus (separate from TFT)...");
  Serial.printf("[SD] Pins: CLK=%d, MISO=%d, MOSI=%d, CS=%d\n", SD_CLK_PIN, SD_MISO_PIN, SD_MOSI_PIN, SD_CS_PIN);

  // Create HSPI instance for SD card - completely separate from TFT's VSPI
  static SPIClass sdSPI(HSPI);
  sdSPI.begin(SD_CLK_PIN, SD_MISO_PIN, SD_MOSI_PIN, SD_CS_PIN);  // CLK=14, MISO=12, MOSI=13, CS=27
  delay(50);

  // Try different SPI speeds
  Serial.println("[SD] Trying 4MHz...");
  sdOK = SD.begin(SD_CS_PIN, sdSPI, 4000000);
  if (!sdOK) {
    Serial.println("[SD] 4MHz failed, trying 1MHz...");
    sdOK = SD.begin(SD_CS_PIN, sdSPI, 1000000);
  }
  if (!sdOK) {
    Serial.println("[SD] 1MHz failed, trying 400kHz...");
    sdOK = SD.begin(SD_CS_PIN, sdSPI, 400000);
  }

  if (sdOK) {
    uint8_t cardType = SD.cardType();
    if (cardType == CARD_NONE) {
      Serial.println("[SD] No card detected!");
      sdOK = false;
    } else {
      uint64_t cardSize = SD.cardSize() / (1024 * 1024);
      Serial.printf("[SD] OK - Card size: %llu MB\n", cardSize);
      Serial.printf("[SD] Card type: %s\n",
        cardType == CARD_MMC ? "MMC" :
        cardType == CARD_SD ? "SD" :
        cardType == CARD_SDHC ? "SDHC" : "UNKNOWN");
      loadConfig();
      displayMode = config.display_mode;  // persisted BLE device_config setting (docs/ble-config.md)
      loadClassRegistry();  // Stage 5.5 — RC-only, no-op for racing boats
      loadIMUCalibration();

      // Append a boot record so we can reconstruct reset history later
      // even without a USB cable attached at the moment of failure.
      File bootLog = SD.open("/boot.log", FILE_APPEND);
      if (bootLog) {
        bootLog.printf("boot fw=%s reset=%s heap=%u min_heap=%u\n",
                       FW_VERSION,
                       resetReasonStr(esp_reset_reason()),
                       ESP.getFreeHeap(),
                       (unsigned)esp_get_minimum_free_heap_size());
        bootLog.close();
        Serial.println("[SD] Boot record appended to /boot.log");
      }
    }
  } else {
    Serial.println("[SD] === SD CARD FAILED ===");
    Serial.println("[SD] Troubleshooting:");
    Serial.println("[SD]   1. Check SD module wiring (CS=GPIO27)");
    Serial.println("[SD]   2. Insert card before power-on");
    Serial.println("[SD]   3. Card must be FAT32 (not exFAT)");
    Serial.println("[SD]   4. Try different SD card");
  }

  // TFT Display - Initialize AFTER SD
  Serial.println("[TFT] Initializing ST7796U...");
  // Backlight via PWM so we can dim during idle. Init at IDLE level —
  // updateBacklight() in the loop pushes to RECORDING when logging starts.
  // Core 3.x ledcAttach: one call attaches a pin with freq + resolution,
  // and ledcWrite addresses the PIN (not a channel) thereafter.
  ledcAttach(TFT_BL_PIN, TFT_BL_PWM_FREQ, TFT_BL_PWM_RES);
  ledcWrite(TFT_BL_PIN, TFT_BL_DUTY_IDLE);
  tft.init();
  tft.setRotation(2);  // Portrait orientation (180° from rotation 0)
  tft.invertDisplay(true);  // Required for correct colors on this ST7796 panel
  tft.fillScreen(COLOR_BG);
  oledOK = true;
  Serial.println("[TFT] ST7796U initialized (320x480 portrait)");

  // SD-card fault gate. If the card never came up, loadConfig() never ran
  // and config.boat_id is still its compile-time default ("E1"). Booting on
  // would put a SECOND "E1" on the mesh — duplicate FNV-1a sender_id —
  // corrupting peer state, OCS, and the class registry (this is exactly how
  // an E6 with a half-seated card silently impersonated E1). Refuse to boot:
  // show a persistent fault screen and stop here, BEFORE meshInit() ever
  // broadcasts a bogus identity. We are past tft.init() but before
  // esp_task_wdt_add(NULL), so the task WDT is not yet armed; the delay()
  // in the loop below still yields to the IDF idle task, keeping its
  // watchdog fed. Recovery is operator action: reseat the card + power-cycle.
  if (!sdOK) {
    tft.fillScreen(COLOR_BG);
    tft.setTextDatum(MC_DATUM);
    tft.setTextColor(COLOR_ERROR, COLOR_BG);
    tft.setTextSize(2);
    tft.drawString("SD CARD", SCREEN_WIDTH/2, 70, 4);
    tft.drawString("FAILURE", SCREEN_WIDTH/2, 125, 4);
    tft.setTextColor(COLOR_TEXT, COLOR_BG);
    tft.setTextSize(1);
    tft.drawString("Contact", SCREEN_WIDTH/2, 215, 4);
    tft.drawString("Paul Avillach", SCREEN_WIDTH/2, 260, 4);
    tft.setTextSize(2);
    tft.drawString("857 891 0512", SCREEN_WIDTH/2, 325, 2);
    tft.setTextSize(1);
    Serial.println("[SD] FATAL: SD unreadable at boot — refusing to start "
                   "(would impersonate default boat_id). Reseat card + power-cycle.");
    while (true) {
      Serial.println("[SD] HALTED: SD card failure — see TFT for contact info.");
      delay(5000);  // yields to idle task so the IDF idle WDT stays fed
    }
  }

  // Splash screen - show device ID, domain, and firmware version
  tft.fillScreen(COLOR_BG);
  tft.setTextDatum(MC_DATUM);

  // Draw device ID in HUGE font (fill most of the screen)
  tft.setTextColor(COLOR_TEXT, COLOR_BG);
  tft.setTextSize(8);
  tft.drawString(config.boat_id, SCREEN_WIDTH/2, SCREEN_HEIGHT/2 - 60, 4);

  // "Sailframes.com" - black, medium size
  tft.setTextColor(TFT_BLACK, COLOR_BG);
  tft.setTextSize(1);
  tft.drawString("Sailframes.com", SCREEN_WIDTH/2, SCREEN_HEIGHT/2 + 80, 4);

  // Firmware version at bottom - large enough to read across the cabin
  tft.setTextColor(COLOR_LABEL, COLOR_BG);
  tft.setTextSize(2);
  tft.drawString(FW_VERSION, SCREEN_WIDTH/2, SCREEN_HEIGHT - 40, 4);
  tft.setTextSize(1);

  delay(2500);  // Show splash screen

  // Reset text size for rest of display
  tft.setTextSize(1);
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
void loop() {
  static unsigned long lastDisp = 0, lastFlush = 0, lastIMU = 0, lastWind = 0;

  esp_task_wdt_reset();  // feed wdt — without this a stuck loop iteration
                         // panics in 300s with a backtrace pointing at the
                         // call that hung (firmware 2026.05.03.01 hard hang)
  g_loopIter++;
  g_loopSection = "top";
  unsigned long now = millis();

  // ----------------------------------------------------------
  // WiFi state management — MUST run before any handler call.
  //
  // (1) Sync wifiConnected with reality. WiFi.setAutoReconnect(false) means
  //     if the iPhone hotspot kicks an idle device, WiFi.status() flips to
  //     WL_DISCONNECTED but our flag stays stale. Calling handleTelnet()
  //     against a dead stack panics the device.
  //
  // (2) Honor teardown requests from the upload task. Core 0 sets the flag
  //     after a successful upload cycle; we tear down here on Core 1 because
  //     we own the handlers. Gated on !uploading && !triggerUpload to avoid
  //     racing a new upload cycle that just kicked off.
  // ----------------------------------------------------------
  // Helper: disconnect from AP without powering down the radio.
  // WiFi.disconnect(true) (wifioff=true) reconfigures the radio, which
  // races with the BLE wind-sensor scanner on the shared ESP32 radio
  // (CLAUDE.md known issues #11/#12) and panicked Core 1 in firmware
  // 2026.05.02.03. WiFi.disconnect(false, false) just leaves the AP —
  // the iPhone hotspot slot is freed, which was the goal — while the
  // radio stays in STA mode so BLE coexistence is undisturbed.
  g_loopSection = "wifi-state-sync";
  // Skip while Core 0 is mid-WiFi-work — these calls go through LWIP and
  // deadlock under contention.
  if (!wifiBusy && wifiConnected && WiFi.status() != WL_CONNECTED) {
    Serial.printf("[WIFI] Lost connection (status=%d) — clearing stale flag\n", WiFi.status());
    Serial.flush();
    g_loopSection = "wifi-state-sync.telnet-stop";
    if (telnetClient && telnetClient.connected()) telnetClient.stop();
    g_loopSection = "wifi-state-sync.server-end";
    telnetServer.end();
    g_loopSection = "wifi-state-sync.wifi-disconnect";
    WiFi.disconnect(false, false);
    connectedSSID[0] = '\0';
    wifiConnected = false;
    wifiTeardownRequested = false;  // Already torn down
  }

  g_loopSection = "wifi-teardown-check";
  if (wifiTeardownRequested && !uploading && !triggerUpload && !wifiBusy && wifiConnected) {
    Serial.println("[WIFI] Honoring teardown request (Core 1)");
    Serial.flush();
    g_loopSection = "teardown.telnet-stop";
    if (telnetClient && telnetClient.connected()) telnetClient.stop();
    g_loopSection = "teardown.server-end";
    telnetServer.end();
    g_loopSection = "teardown.wifi-disconnect";
    WiFi.disconnect(false, false);
    connectedSSID[0] = '\0';
    wifiConnected = false;
    wifiTeardownRequested = false;
    Serial.println("[WIFI] Teardown complete");
    Serial.flush();
  }

  // Telnet is skipped while wifiBusy: handleTelnet's WiFiServer/WiFiClient
  // calls share LWIP locks with Core 0's HTTP uploads and deadlock under
  // sustained contention (firmware 2026.05.03.03 hang).
  if (wifiConnected && !wifiBusy) {
    g_loopSection = "telnet";
    handleTelnet();
  }

  // BLE relay runs independent of WiFi state — it's not gated on wifiBusy
  // like the central wind-sensor scan (pauseBLEForWiFi()): GATT-server
  // notify/write servicing doesn't share NimBLEScan's documented
  // WiFi-contention hang, and pausing it here would drop an in-flight
  // phone relay transfer every time the device happens to also do a
  // periodic WiFi health check.
  g_loopSection = "ble-relay";
  bleRelayTick();

  g_loopSection = "mesh";
  meshTick();

  g_loopSection = "ocs";
  ocsTick();

  g_loopSection = "rc-ocs";
  rcComputeFleetOCS();

  g_loopSection = "fleetwatch";
  fleetWatchTick();

  g_loopSection = "serial-cmd";
  handleSerialCommand();


  g_loopSection = "gps";
  if (config.rtk_enabled && roleIsBase()) readGPSBase();   // demux RTCM-out + 1 Hz NMEA
  else                                    readGPS();        // unchanged NMEA-only path

  // RTK Phase-2 — rover: drain reassembled RTCM from the ring (filled in the
  // ESP-NOW recv callback) to the GNSS UART. Bounded + non-blocking: write only
  // what fits the UART TX buffer this iteration, never flush a backlog.
  if (config.rtk_enabled && roleIsRover() && g_rtcmRing) {
    g_loopSection = "rtcm-drain";
    uint8_t tmp[256];
    for (int budget = 4; budget > 0; budget--) {
      int canWrite = Serial2.availableForWrite();
      if (canWrite <= 0) break;
      if (canWrite > (int)sizeof(tmp)) canWrite = sizeof(tmp);
      size_t n = xStreamBufferReceive(g_rtcmRing, tmp, (size_t)canWrite, 0);
      if (n == 0) break;
      Serial2.write(tmp, n);
    }
  }

  // Once per boot: when GPS time first becomes valid, stamp boot.log with
  // wall-clock + battery so we can correlate this session with the previous
  // "alive" tail and tell battery-died from clean-power-off.
  if (!g_bootSessionLogged) {
    char iso[24];
    if (formatGpsIso(iso, sizeof(iso))) {
      char line[80];
      snprintf(line, sizeof(line), "session t=%s batt=%.2fV %d%%",
               iso, battery.voltage, battery.percent);
      appendBootLog(line);
      g_bootSessionLogged = true;
    }
  }

  g_loopSection = "button";
  buttonTick();

  // Sensor reads are I2C on Core 1, upload runs on Core 0 — no conflict.
  // SD logging (logIMU/logPressure) is guarded by `logging` which is always
  // false during upload (task checks !logging before starting).
  if (now - lastIMU >= IMU_INTERVAL_MS) {
    g_loopSection = "imu";
    readIMU();
    if (logging) { g_loopSection = "imu.log"; logIMU(); }
    lastIMU = now;
  }

  // Pressure sensor (0.1 Hz - weather trends only, not gust detection)
  static unsigned long lastPres = 0;
  if (presOK && now - lastPres >= PRES_INTERVAL_MS) {
    g_loopSection = "pres";
    readPressure();
    if (logging) { g_loopSection = "pres.log"; logPressure(); }
    lastPres = now;
  }

  // Reset pressure min/max every 10 seconds for fresh gust window
  static unsigned long lastPresReset = 0;
  if (presOK && now - lastPresReset >= 10000) {
    g_loopSection = "pres-reset";
    resetPressureMinMax();
    lastPresReset = now;
  }

  if (logging && gps.newGGA) {
    g_loopSection = "nav.log";
    logNav();
    gps.newGGA = false;
  }

#if ENABLE_WIND
  // Handle wind sensor
  if (config.wind_enabled) {
    g_loopSection = "wind-check";
    checkWindConnection();

    // Log wind data at configured interval
    if (logging && now - lastWind >= WIND_INTERVAL_MS) {
      g_loopSection = "wind.log";
      logWind();
      lastWind = now;
    }
  }
#endif

  // The OCS alarm blinks at ~2 Hz (inverts every 250 ms); the normal 500 ms
  // display cadence is too slow to render that (and aliases to a static
  // frame), so tick the display ~every 120 ms while the alarm is up. The RC
  // fleet panel also wants a faster, live refresh.
  bool fastDisp = (g_ocs.armed && g_ocs.over_line) ||
                  (g_role == ROLE_RC_SIGNAL && g_ocs.armed);
  unsigned long dispGate = fastDisp ? 120 : DISPLAY_UPDATE_MS;
  if (now - lastDisp >= dispGate) {
    g_loopSection = "display";
    updateDisplay();
    // Adaptive backlight — recheck at every display tick, only write
    // PWM register when target changes (effectively at logging
    // start/stop). Saves ~30% of backlight current during idle.
    static uint8_t bl_current = TFT_BL_DUTY_IDLE;
    uint8_t bl_target = logging ? TFT_BL_DUTY_RECORDING : TFT_BL_DUTY_IDLE;
    if (bl_target != bl_current) {
      ledcWrite(TFT_BL_PIN, bl_target);
      bl_current = bl_target;
    }
    lastDisp = now;
  }

  if (logging && now - lastFlush >= FLUSH_INTERVAL_MS) {
    navFile.flush();
    if (imuFile) imuFile.flush();
#if ENABLE_WIND
    if (windFile) windFile.flush();
#endif
    if (presFile) presFile.flush();
    lastFlush = now;
  }

  // WiFi upload is handled entirely by uploadTaskFunc on Core 0
  // (removed checkWiFiUpload from main loop — was causing race condition crashes)

  // Battery monitoring (every 10 seconds)
  static unsigned long lastBattCheck = 0;
  if (now - lastBattCheck >= 10000) {
    g_loopSection = "battery";
    updateBattery();
    handleLowBattery();  // Will warn and halt if critical
    lastBattCheck = now;
  }
  g_loopSection = "loop-end";

  // RTCM3 debug output (every 30 seconds) - helps diagnose PPK data logging
  static unsigned long lastRtcmDebug = 0;
  if (now - lastRtcmDebug >= 30000) {
    // RTCM3 stats tracked but not printed (use 'status' command to see)
    lastRtcmDebug = now;
  }
}

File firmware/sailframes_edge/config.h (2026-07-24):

// SailFrames E1 — pin assignments, firmware-wide constants, and the
// on-SD-card Config struct (config.txt). Split out of the original
// monolithic sailframes_edge.ino so every module can pull in the
// constants it needs without depending on the whole sketch.
#ifndef SAILFRAMES_CONFIG_H
#define SAILFRAMES_CONFIG_H

#include <Arduino.h>

// ============================================================
// PIN DEFINITIONS
// ============================================================
#define GPS_RX_PIN    16
#define GPS_TX_PIN    17
#define SDA_PIN       21
#define SCL_PIN       22

// TFT Display (Hosyond 3.5" IPS ST7796U) - SPI
#define TFT_CS_PIN    5   // LCD chip select
#define TFT_DC_PIN    2   // Data/Command (also used as LED_PIN on old board)
#define TFT_RST_PIN   4   // LCD reset
#define TFT_BL_PIN    25  // Backlight PWM

// Adaptive backlight (2026.05.26.04). Backlight is the dominant load
// in the power budget (~40% of total system draw). Dimming when not
// recording recovers ~30% of backlight current during the "between
// sails / pre-start" idle periods, gaining ~10-15% of total system
// runtime. Levels chosen per operator preference: 80% gives plenty of
// daylight readability while shaving 20% off the recording-mode
// backlight current; 50% is still legible in shade and saves half the
// idle backlight current.
//
// Uses the ESP32 Arduino Core 3.x ledcAttach API (pin-addressed), NOT
// the legacy 2.x ledcSetup/ledcAttachPin channel-addressed API which
// doesn't exist in Core 3.3.7.
#define TFT_BL_PWM_FREQ     5000   // 5 kHz — well above flicker perception
#define TFT_BL_PWM_RES      8      // 8-bit duty (0-255)
#define TFT_BL_DUTY_RECORDING 204  // ~80%
#define TFT_BL_DUTY_IDLE      128  // ~50%

// SD Card - standalone module on SEPARATE HSPI bus (eliminates TFT flicker)
// HSPI pins - completely independent from TFT's VSPI bus
// NOTE: GPIO12 is a strapping pin - avoid it! Using GPIO35 for MISO instead
#define SD_CS_PIN     27  // SD card CS (GPIO27)
#define SD_CLK_PIN    14  // HSPI CLK
#define SD_MISO_PIN   35  // MISO on GPIO35 (input-only pin, perfect for MISO)
#define SD_MOSI_PIN   13  // HSPI MOSI

// LED_PIN disabled - was causing backlight to blink during logging
#define LED_PIN       -1  // Set to -1 to disable LED blinking

// Battery monitoring (DWEII USB-C Boost Converter)
// 100K/100K voltage divider from LiPo B+ to GPIO34
#define BATT_VOLTAGE_PIN  34   // ADC pin for voltage divider (input-only, no pullup)

// Recording/pairing momentary pushbutton — active-low, other leg to GND,
// internal pull-up (no external resistor needed). See button.h/.cpp and
// docs/hardware.md.
#define BUTTON_PIN            32
#define BUTTON_DEBOUNCE_MS    30     // raw-level settle time before accepting an edge
#define BUTTON_LONG_PRESS_MS  2000   // held past this = long press (opens BLE pairing window)
#define BLE_BOND_WINDOW_MS    60000  // how long a long-press keeps new-phone bonding open

// Power control: Hardware switch on boost converter.
// No software deep sleep - hardware switch cuts all power when OFF.

// ============================================================
// CONFIGURATION
// ============================================================
// Firmware version: YYYY.MM.DD.N (date + daily build number)
#define FW_VERSION    "2026.06.29.02"   // E (LG290P)

// v2.0.0 foundation: HW platform / unit role / radio mode skeleton.
// 10 Hz GNSS + 10 Hz IMU are now baked-in firmware defaults (no longer
// per-boat config knobs). config.txt holds per-boat / per-club state
// only (WiFi creds, boat_id, wind sensor, role, etc.).

// Telnet listener is OFF by default. The 2026.05.03.04 fleet test confirmed
// (via diag heartbeat) that handleTelnet() blocks Core 1 inside LWIP when
// Core 0 is doing concurrent HTTP uploads — even with the wifiBusy gate,
// because Core 1 may already be INSIDE handleTelnet when the upload fires
// and the gate only prevents new entries. Easiest robust fix: don't run
// the listener during automated post-sail uploads. Set telnetEnabled=true
// at runtime via the serial 'telneton' command if you need to debug live.
#define TELNET_ENABLED_DEFAULT  false

#define GPS_BAUD      460800  // LG290P configured rate
#define SERIAL_BAUD   115200
#define SCREEN_WIDTH  320     // E1: 3.5" ST7796 portrait width
#define SCREEN_HEIGHT 480     // E1: 3.5" ST7796 portrait height
#define BNO085_ADDR   0x4B    // GY-BNO08X breakout (ADO pin high)
#define DPS310_ADDR   0x77    // Pressure/temperature sensor
#define GPS_FIX_TIMEOUT_MS  300000
#define DISPLAY_UPDATE_MS   500   // TFT can handle faster updates (no I2C contention)
#define FLUSH_INTERVAL_MS   10000
#define IMU_INTERVAL_MS     100    // 10 Hz BNO085 reports. Baked-in fleet default.
#define PRES_INTERVAL_MS    10000  // 0.1 Hz (every 10 sec - weather trends only)
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

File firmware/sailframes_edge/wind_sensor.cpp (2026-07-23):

// Calypso Mini wind sensor (BLE) glue — see wind_sensor.h.
#include "wind_sensor.h"
#include "config.h"
#include "gnss.h"
#include "storage.h"
#include "display.h"
#include "upload.h"
#include "shared_state.h"

// Calypso BLE UUIDs (Environmental Sensing Service 0x181A)
static NimBLEUUID WIND_SERVICE_UUID("181A");
static NimBLEUUID WIND_SPEED_CHAR_UUID("2A72");      // Apparent Wind Speed (uint16, m/s * 100)
static NimBLEUUID WIND_DIR_CHAR_UUID("2A73");        // Apparent Wind Direction (uint16, degrees * 100)
static NimBLEUUID BATTERY_SERVICE_UUID("180F");
static NimBLEUUID BATTERY_CHAR_UUID("2A19");         // Battery Level (uint8, 0-100%)

// Calypso Data Service (0x180D) - combined wind+battery in single notification
// Format: [speed_lo, speed_hi, dir_lo, dir_hi, battery] where battery * 10 = %
static NimBLEUUID DATA_SERVICE_UUID("180D");
static NimBLEUUID DATA_CHAR_UUID("2A39");            // Combined wind+battery (5 bytes)

// Device Information Service (0x180A) - for reading firmware version
static NimBLEUUID DEVINFO_SERVICE_UUID("180A");
static NimBLEUUID FIRMWARE_CHAR_UUID("2A26");        // Firmware Revision String

WindData wind;
bool windScanning = false;
bool windOK = false;
bool bleInitialized = false;

// BLE client for Calypso wind sensor
static NimBLEClient* pWindClient = nullptr;
static NimBLERemoteCharacteristic* pWindSpeedChar = nullptr;
static NimBLERemoteCharacteristic* pWindDirChar = nullptr;
static NimBLERemoteCharacteristic* pBatteryChar = nullptr;
static NimBLERemoteCharacteristic* pDataChar = nullptr;      // Combined wind+battery (0x2A39)
static unsigned long lastWindScan = 0;

void windSpeedNotifyCallback(NimBLERemoteCharacteristic* pChar, uint8_t* pData, size_t length, bool isNotify) {
  if (length >= 2) {
    uint16_t raw = pData[0] | (pData[1] << 8);
    wind.speed_mps = raw / 100.0;
    wind.speed_kts = wind.speed_mps * 1.94384;
    wind.newData = true;
    wind.lastUpdate = millis();
  }
}

// BLE notification callback for wind direction
void windDirNotifyCallback(NimBLERemoteCharacteristic* pChar, uint8_t* pData, size_t length, bool isNotify) {
  if (length >= 2) {
    uint16_t raw = pData[0] | (pData[1] << 8);
    wind.angle_deg = raw / 100;  // 0.01 degree resolution
    wind.newData = true;
    wind.lastUpdate = millis();
  }
}

// BLE notification callback for battery (0x180F / 0x2A19)
void batteryNotifyCallback(NimBLERemoteCharacteristic* pChar, uint8_t* pData, size_t length, bool isNotify) {
  if (length >= 1) {
    wind.battery = pData[0];
  }
}

// BLE notification callback for combined Data Service (0x180D / 0x2A39)
// Format: [speed_lo, speed_hi, dir_lo, dir_hi, battery] where battery * 10 = %
void dataNotifyCallback(NimBLERemoteCharacteristic* pChar, uint8_t* pData, size_t length, bool isNotify) {
  if (length >= 5) {
    uint16_t speedRaw = pData[0] | (pData[1] << 8);
    uint16_t dirRaw = pData[2] | (pData[3] << 8);
    uint8_t battRaw = pData[4];

    wind.speed_mps = speedRaw / 100.0;
    wind.speed_kts = wind.speed_mps * 1.94384;
    wind.angle_deg = dirRaw;
    wind.battery = battRaw * 10;  // Manual says value * 10 = %
    wind.newData = true;
    wind.lastUpdate = millis();
  }
}

// BLE client callbacks
class WindClientCallbacks : public NimBLEClientCallbacks {
  void onConnect(NimBLEClient* pClient) {
    Serial.println("[WIND] BLE connected");
    wind.connected = true;
  }

  void onDisconnect(NimBLEClient* pClient) {
    Serial.println("[WIND] BLE disconnected");
    wind.connected = false;
    windOK = false;
    pWindSpeedChar = nullptr;
    pWindDirChar = nullptr;
    pBatteryChar = nullptr;
    pDataChar = nullptr;
  }
};

static WindClientCallbacks windClientCallbacks;

// Save discovered MAC to config for faster reconnection
void saveWindMAC(const char* mac) {
  strncpy(config.wind_mac, mac, sizeof(config.wind_mac) - 1);

  // Save to SD card
  File f = SD.open("/wind_mac.txt", FILE_WRITE);
  if (f) {
    f.println(mac);
    f.close();
    Serial.printf("[WIND] Saved MAC %s for auto-reconnect\n", mac);
  }
}

// Load wind MAC from SD - if /wind_mac.txt exists, enable wind sensor
void loadWindMAC() {
  File f = SD.open("/wind_mac.txt", FILE_READ);
  if (f) {
    String mac = f.readStringUntil('\n');
    mac.trim();
    if (mac.length() >= 17) {  // Valid MAC is 17 chars (XX:XX:XX:XX:XX:XX)
      mac.toCharArray(config.wind_mac, sizeof(config.wind_mac));
      config.wind_enabled = true;
      Serial.printf("[WIND] Loaded MAC from SD: %s - wind ENABLED\n", config.wind_mac);
    } else {
      Serial.println("[WIND] /wind_mac.txt exists but invalid MAC format");
    }
    f.close();
  } else {
    Serial.println("[WIND] No /wind_mac.txt on SD - wind DISABLED");
  }
}
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

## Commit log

2026-07-23 Bootstrap xgsail-e1 from sailframes/core's E1 device (edge-e)
    Extracts the E1 firmware and KiCad hardware from fforzano/xgsail's own
    fork history (commit 0bb4b45, the last point before the software-platform
    redesign removed edge-e/edge-b/edge-s), restricted to E1 only. The
    firmware is refactored from a single 8450-line sketch into one file pair
    per responsibility (gnss, mesh, imu, wind sensor, pressure, battery,
    recording, OCS, display, storage, OTA, console, cloud config, upload),
    with the B1-successor-hardware #ifdef branches removed since this repo
    is E1-only. CLAUDE.md and README mirror xgsail's structure and document
    the derivation from sailframes/core.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
    [E1_BOM.csv, config.txt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]
2026-07-23 Add curated architecture/GNSS-RTK/hardware docs
    Reconciles the historical E1 design notes (some describe superseded
    hardware revisions, some describe features from a forward-looking spec
    doc) against the actual shipped firmware source, and consolidates them
    into three current-state references instead of a pile of dated update
    notes.
    Claude-Session: https://claude.ai/code/session_017rYm1Dc1XYMv3FkTep3Mt2
2026-07-23 Update E1 firmware to xgsail's current device-integration protocol
    Rewrites the upload/identity layer to match xgsail's docs/device-protocol.md:
    claim flow (device_auth.h/.cpp), DeviceKey-authenticated session-uploads API
    (upload.cpp), and a BLE GATT relay (ble_relay.h/.cpp) as a first-class
    WiFi-independent upload path, always advertising rather than a fallback.
    No backward compatibility kept, per direction — this is the first refactor
    onto the new protocol:
    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
    [config.txt]
2026-07-23 Add BLE remote configuration + IMU calibration
    Extends the existing device-protocol BLE GATT relay (ble_relay.cpp) with
    a new device_config characteristic (E1-specific, alongside xgsail's
    documented protocol on the same service) so a companion app can read and
    write WiFi credentials, boat_id, unit_role, wind sensor MAC/offset,
    recording thresholds, and RTK enable — all live, no reboot required, via
    small refresh helpers each owning module now exposes
    (applyUnitRole/applyRecordingThresholds/forceWindReconnect/gnssConfigure/
    boatIdHash). WiFi passwords are write-only, never echoed back on read.
    control gains two commands (calibrate/calibrate-reset) reusing the same
    calibrateIMU()/resetIMUCal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
    [ble_relay.cpp, config.cpp, config.h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]
2026-07-23 Add read-only BLE status characteristic
    New status characteristic (read-only, on demand, no bonding required)
    exposing live runtime state over BLE: claim status, firmware version,
    uptime/heap, battery, SD health, WiFi connection, sensor presence
    (IMU/pressure/wind), live GPS fix/position/speed, live wind reading, and
    recording activity (logging/session count/pending uploads).
    Distinct from device_config (how the device is configured) and identity
    (stable identity) — this is current state, mirroring exactly what the
    console's `status` command already prints, just as JSON. Pure read of
    already-maintained in-memory globals, no SD access, so no sdMutex needed
    unlike the other BLE characterist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
    [ble_relay.cpp]
2026-07-23 Add button-triggered recording + BLE pairing window
    Recording start/stop was GPS-speed-triggered; switch it to a manual
    short-press on a new physical button (button.{h,cpp}, GPIO32), the
    existing console rec/stoprec commands, and two new BLE control
    commands (start-rec/stop-rec) — all routed through recording.h's new
    startRecording()/stopRecording()/toggleRecording() instead of the old
    per-file duplicated start/stop logic. Simplifies RecordState to
    IDLE/RECORDING (drops the now-unreachable ARMED/STOPPING states).
    A long press on the same button opens a 60s BLE pairing window
    (ble_relay.cpp's bleOpenBondWindow()): bonding is off by default, so a
    phone that isn't already bonded can't write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
    [ble_relay.cpp, button.cpp, config.h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]
2026-07-23 Let a session's boat/activity be chosen at recording start, not just claim time
    E1 devices only ever uploaded under device.owner_boat_id / a fresh solo
    activity — the backend's session-uploads already accepts per-call
    boat_id/activity_id overrides (unused by this firmware until now).
    Thread them through: startLogging() writes optional boat_id.txt/
    activity_id.txt markers into the session folder, upload.cpp reads them
    back onto the session-uploads POST, and the BLE relay's start-rec
    control command (and session_manifest, for the relay path) exposes both
    as optional fields — the app picks them when it triggers a recording,
    with no-value falling back to today's defaults unchanged.
    Also fix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
    [ble_relay.cpp, recording.cpp, storage.cpp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]
2026-07-23 Fix pre-existing build errors — first successful arduino-cli compile
    The modular per-responsibility split had apparently never been build-
    verified end-to-end: compiling with arduino-cli (ESP32 core 3.3.7,
    pinned library set) surfaced ~67 errors, all pre-existing (confirmed by
    rebuilding the prior commit in isolation — identical failures, unrelated
    to any recent feature work). Fixes, one per root cause:
    - rtk_relay.h: stream_buffer.h was included before FreeRTOS.h (wrong
    order breaks BaseType_t/TickType_t); missing <Arduino.h> for millis().
    - rtk_relay.cpp: missing includes for wifiBusy (shared_state.h) and
    esp_now_send (esp_now.h).
    - wind_sensor.cpp: a stray #endif with no matching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
    [console.cpp, storage.cpp, wind_sensor.cpp]
2026-07-24 Add auto-cleanup after upload and session elapsed time
    Uploaded session files stuck around on the SD card indefinitely unless
    an operator ran the manual `cleanup`/`delup` console command — fine for
    a season of light use, but avoidable busywork by default. Add
    config.auto_cleanup_uploads (default true, config.txt-persisted and
    live-settable over BLE's device_config): upload.cpp's WiFi path and
    ble_relay.cpp's ack-uploaded (BLE relay path) both now delete a file +
    its .uploaded marker right after a confirmed upload, through one shared
    cleanupIfAutoDelete() so the two paths can't diverge. `cleanup`/`delup`
    stay available as a manual fallback (auto-cleanup off, or a cleanup that
    didn't run bec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
    [config.txt]
2026-07-24 Add BLE-configurable display mode; document + illustrate TFT screens
    - config.txt's new display_mode field (1-3) persists the nav display
    mode across reboots; exposed read/write on the device_config BLE
    characteristic alongside the existing live-apply fields.
    - Add pixel-accurate renders of D1/D2/D3 and the two RC-only panels
    under docs/images/display-modes/, referenced from README.md and
    docs/hardware.md's Display section.
    [config.txt]
2026-07-24 Add @xgsail-e1/capacitor: reusable BLE client + device management SDK
    Extracts the E1's BLE transport (GATT UUIDs, config/status, calibration,
    session-relay) and claim/upload orchestration into a standalone,
    backend-agnostic TypeScript package under clients/ — so any Capacitor app
    managing an E1 can reuse it instead of reimplementing the protocol, with
    its own npm release workflow independent of the firmware.
2026-07-24 Derive @xgsail-e1/capacitor's published version from the release tag
    package.json's committed "version" was a second source of truth that had
    to be kept in sync with the tag by hand; the workflow now reads it off
    the tag itself (capacitor-vX.Y.Z) right before build/publish instead.
2026-07-24 Add OTA firmware updates: dual-app partitions, manifest fetch/verify/apply, manual BLE trigger
    Switches the build to a custom dual-app partition table (partitions.csv)
    so the device can flash the inactive OTA slot instead of requiring a USB
    reflash. checkForFirmwareUpdate() (upload.cpp) fetches
    <ota_base_url>/manifest.json (same shape as xgsail's ota-service),
    compares FW_VERSION, and on a newer build streams + SHA256-verifies the
    image before committing and rebooting. Runs once per boot when
    ota_auto_update is on, or on demand via a new BLE control command
    (ota-update) usable from any bonded phone regardless of that setting.
    Never starts, and suspends if already running, while a recording i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
    [config.txt, partitions.csv]
